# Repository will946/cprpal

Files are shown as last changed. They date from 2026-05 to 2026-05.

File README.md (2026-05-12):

# CPRPal — Real-Time CPR Feedback and Training Device

---

## Table of Contents

- [Project Overview](#project-overview)
- [Repository Structure](#repository-structure)
- [System Architecture](#system-architecture)
- [Hardware Components](#hardware-components)
- [Wiring and Pin Assignments](#wiring-and-pin-assignments)
- [PCB Design](#pcb-design)
- [Firmware](#firmware)
- [Operating Modes](#operating-modes)
- [User Operation](#user-operation)
- [Signal Processing](#signal-processing)
- [Power System](#power-system)
- [Cloud and Web Application](#cloud-and-web-application)
- [Setup and Installation](#setup-and-installation)
- [Library Dependencies](#library-dependencies)

---

## Project Overview

CPRPal is a portable, puck-shaped CPR coaching device designed to help untrained bystanders and CPR trainees perform chest compressions with correct force, rhythm, and body positioning during a cardiac emergency or training session.

Sudden cardiac arrest is responsible for approximately 93% of out-of-hospital cardiac arrest deaths. Survival probability drops roughly 10% per minute without CPR or AED intervention, yet only about 3% of the U.S. population is CPR certified annually. CPRPal addresses this gap by providing real-time, easy-to-interpret feedback that requires no prior training to use.

The device is placed between the rescuer's hands and the patient's sternum during chest compressions. It measures compression force directly using a load cell, tracks body posture using a 9-DOF IMU, monitors for heartbeat presence using a PPG optical sensor, and delivers feedback through a color-coded NeoPixel LED ring, a 2.8" TFT LCD display, and a 100 BPM audio metronome buzzer.

**Emergency Mode** operates fully standalone with no Wi-Fi required, providing immediate real-time feedback the moment the button is pressed.

**Training Mode** connects to Wi-Fi, runs a 2-minute guided session, and uploads averaged session metrics to an Azure-hosted cloud dashboard for review.

The final prototype measures 4.5" x 4.5" x 2.25" and runs for over 15 hours on four AA batteries at a normal operating draw of approximately 155 mA.

CPRPal Demo: https://drive.google.com/file/d/1d1auYhc-_jhG4WK9BlywpUfyi4_rIxLO/view?usp=sharing
(Note video isn't perfectly sync with operation)

| Rendering | Final Build |
|---|---|
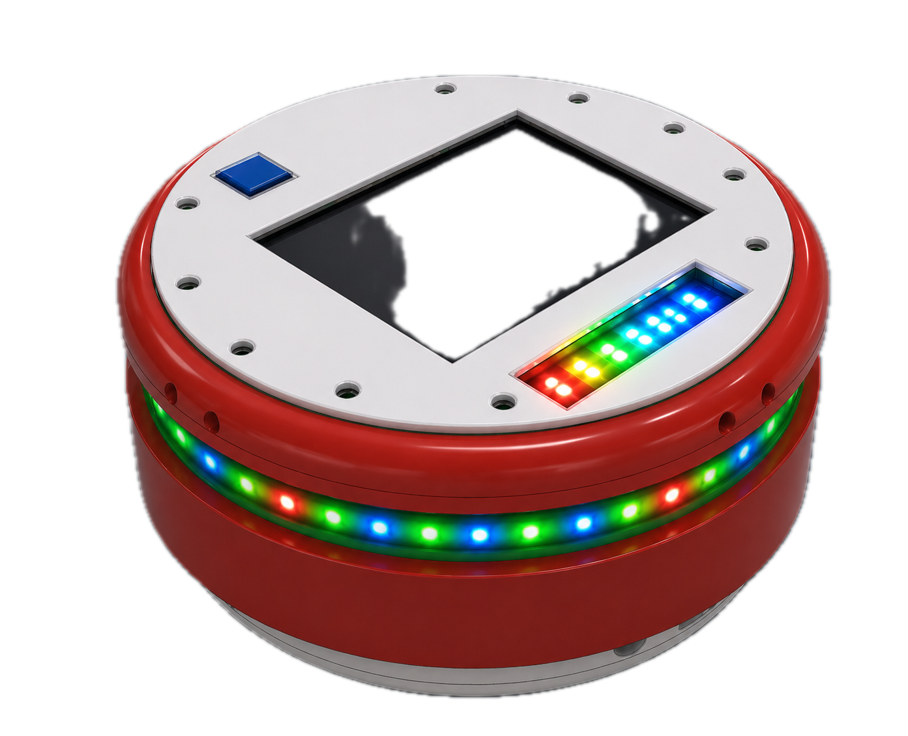
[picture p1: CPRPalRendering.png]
CPRPal Rendering
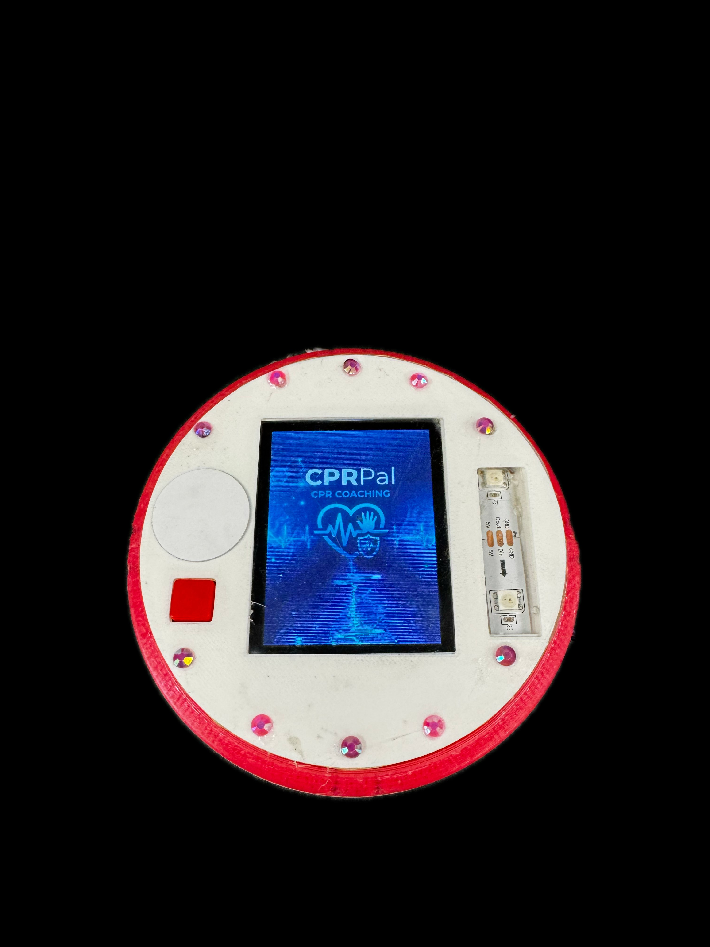
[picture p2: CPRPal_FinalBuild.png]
CPRPal Final Build
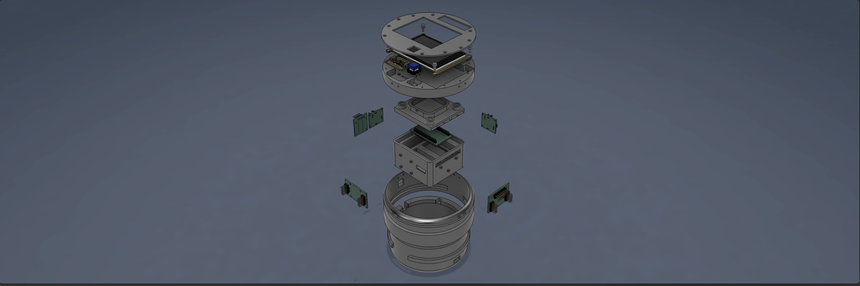
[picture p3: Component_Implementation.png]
Exploded View
|  |  | 

---

## Repository Structure

```
CPRPal/
├── 3DModel/
│   └── Mechanical enclosure and CAD files
│       - Top shell with lattice structure and LCD/button/LED cutouts
│       - Bottom shell with battery pocket, support beams, and hard stops
│       - Full assembly files for PLA 3D printing
│
├── ArduinoCode/
│   └── CPRPal.ino — Main ESP32 firmware (FreeRTOS-based)
│       - Sensor integration (HX711, BNO055, PPG)
│       - Real-time signal processing and CPM detection
│       - LED and display feedback systems
│       - Emergency and Training mode logic
│       - Power management and idle sleep
│       - HTTP cloud upload for training sessions
│
├── ArduinoWebsite/
│   └── Azure Static Web App source code
│       - Frontend dashboard (HTML/CSS/JS)
│       - Azure Function API endpoint
│       - Receives HTTP POST from ESP32
│       - Displays training session summary
│
├── PartsList/
│   └── Bill of Materials (BOM) and component references
│
└── PCBFiles/
    └── Full circuit schematics and PCB layout files
        - CPRPal_PCB_Sch — complete schematic
        - Panelized 6-board layout for JLCPCB fabrication
        - Custom PCB footprints and 3D component models
```

---

## System Architecture

CPRPal uses a dual-core FreeRTOS architecture on the Arduino Nano ESP32-S3.

### Core 0 — Sensor Acquisition and Processing

All time-critical sensor tasks run on Core 0 to prevent display rendering overhead from introducing jitter into sensor sampling.

| Task | Function | Sample Rate |
|---|---|---|
| `taskHX711` | Load cell reading, EMA filtering, CPM detection, idle detection | ~80 Hz |
| `taskIMU` | BNO055 orientation reading, tilt computation, posture status | ~40 Hz |
| `taskPPG` | PPG sampling, adaptive peak detection, BPM estimation | ~50 Hz |
| `taskBuzzer` | 100 BPM metronome via LEDC PWM, rhythm LED strip sync | 100 BPM |

### Core 1 — User Interface and Control

The Arduino `loop()` function runs on Core 1 and handles all output rendering:

- TFT display refresh at 10 Hz
- NeoPixel force bar graph refresh at 40 Hz
- Mode selection and session control logic
- Training session timer and metric accumulation
- Serial calibration commands

### Shared State and Synchronization

All shared sensor variables use the `g_` prefix, are declared `volatile`, and are protected by the FreeRTOS mutex `xDataMutex`. A second mutex `xWireMutex` serializes I2C bus access between `taskIMU` and any other bus user. This two-mutex architecture prevents data races while minimizing lock hold time.

---

## Hardware Components

| Component | Part | Purpose |
|---|---|---|
| Microcontroller | Arduino Nano ESP32-S3 | Main processing, Wi-Fi, dual-core FreeRTOS |
| Force Sensor | Half-bridge strain gauge load cell (120 lb) | Direct compression force measurement |
| Load Cell Amplifier | HX711 24-bit ADC | Amplifies and digitizes load cell signal at 80 SPS |
| IMU | Adafruit BNO055 9-DOF Fusion Breakout | Orientation, tilt detection, motion artifact rejection |
| Pulse Sensor | Pulse Sensor Amped (PPG) | Supplemental heartbeat detection |
| Display | Adafruit 2.8" ILI9341 TFT LCD | Real-time prompts and numeric status |
| LED Strips | Adafruit NeoPixel WS2812B (18 total) | Force bar (15 px) and rhythm metronome (3 px) |
| Buzzer | Piezo buzzer | 100 BPM audio metronome |
| Power Regulation | TPS63070 buck-boost converter x2 | Regulated 3.3V and 5V rails from 4xAA batteries |
| Reverse Protection | LM66200 ideal diode x2 | Prevents USB-to-battery reverse current |
| Storage | SanDisk 32GB microSD | Boot animation BMP frames |
| Battery | 4xAA alkaline | 10+ hours runtime at normal operating load |
| Enclosure | PLA 3D print | 4.7" x 4.7" x 2.4" puck housing |

---

## Wiring and Pin Assignments

### ESP32 GPIO Map

| Pin | Peripheral | Function |
|---|---|---|
| GPIO2 | HX711 CLK | Load cell clock |
| GPIO3 | HX711 DOUT | Load cell data |
| GPIO4 | SD Card CS | microSD chip select |
| GPIO6 (D6) | Start Button | Mode selection (active low, internal pull-up) |
| GPIO9 | ILI9341 DC | TFT data/command select |
| GPIO10 | ILI9341 CS | TFT chip select |
| GPIO19 | Buzzer | LEDC PWM channel 0, 2 kHz |
| GPIO21 | PPG LED indicator | Heartbeat flash LED |
| GPIO23 | PPG Sensor | Analog ADC input |
| GPIO2 (LED_PIN) | NeoPixel force bar | 15-pixel WS2812B data |
| GPIO4 (RHYTHM) | NeoPixel rhythm strip | 3-pixel WS2812B data |
| A4 (SDA) | BNO055 SDA | I2C data, 400 kHz |
| A5 (SCL) | BNO055 SCL | I2C clock, 400 kHz |

### I2C Bus

- BNO055 IMU address 0x28
- 10 kOhm pull-up resistors on SDA and SCL
- Bus speed 400 kHz (fast mode)
- External 32.768 kHz crystal for improved BNO055 sensor fusion accuracy

### SPI Bus

- ILI9341 TFT LCD: DC on GPIO9, CS on GPIO10
- microSD: CS on GPIO4
- Both share the hardware SPI bus

### Load Cell Wiring (Half-Bridge)

| Wire Color | HX711 Pin | Function |
|---|---|---|
| RED | E+ | Excitation positive |
| BLACK | E- | Excitation negative |
| WHITE | A- | Signal negative (differential) |
| GREEN | A+ | Signal positive (differential) |
| YELLOW | GND | Common ground reference |

Two 1 kOhm resistors on the HX711 board complete the Wheatstone bridge by providing the two fixed-impedance legs of the half-bridge configuration.

---

## PCB Design

CPRPal uses a custom panelized PCB fabricated by JLCPCB, separated into six press-fit sub-boards using mouse-bite breakaway tabs. Each sub-board can be removed and replaced independently without additional soldering.

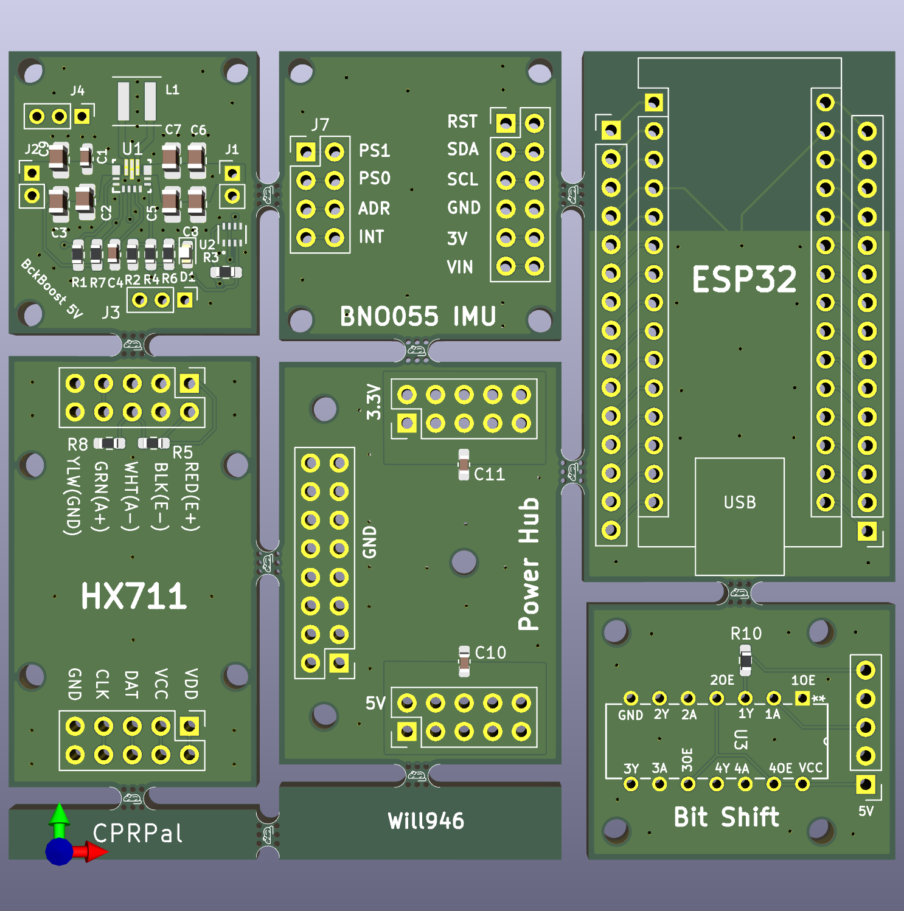
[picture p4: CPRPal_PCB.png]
PCB Panel Layout


### Sub-Board Summary

| Board | Key Components | Output |
|---|---|---|
| 3.3V BuckBoost | TPS63070, LM66200, 213k/365k feedback divider, decoupling caps, 1.5uH inductor | Regulated 3.3V rail |
| 5V BuckBoost | TPS63070, LM66200, alternate feedback divider, decoupling caps, 1.5uH inductor | Regulated 5V rail |
| Power Hub | Distribution headers, 10uF X5R decoupling caps x2 | Common power and ground plane |
| HX711 | HX711 IC, 1kOhm bridge resistors, DOUT/CLK headers | Load cell ADC interface |
| BNO055 IMU | BNO055 breakout, 10kOhm I2C pull-ups, 32.768kHz crystal | Euler angle outputs via I2C |
| ESP32 | Nano ESP32-S3 socket, USB passthrough | Main MCU |
| Bit Shift | Logic level shifter | 3.3V to 5V NeoPixel data translation |

### Component Footprints

#### 3.3V and 5V BuckBoost Boards
| Reference | Component | Footprint |
|---|---|---|
| U1 | TPS63070 — Buck-boost converter | SOT-23-8 |
| U2 | LM66200 — Ideal diode controller | SOT-23-6 |
| L1 | 1.5 µH inductor | Inductor_SMD 4x4mm |
| R1, R2 | Feedback divider resistors (213k / 365k for 3.3V; alternate values for 5V) | 0402 |
| R3 | Current sense resistor | 0402 |
| R4, R6, R7 | Bias/compensation resistors | 0402 |
| C1–C6 | Decoupling and compensation capacitors | 0402 |
| C7 | Output bulk capacitor | 0805 |
| D1 | Schottky diode | SOD-123 |
| J1, J2, J3, J4 | Power input/output headers | PinHeader 1x02 2.54mm |

#### Power Hub Board
| Reference | Component | Footprint |
|---|---|---|
| C10, C11 | 10 µF X5R decoupling capacitors | 0805 |
| J (3.3V) | 3.3V distribution header | PinHeader 2x05 2.54mm |
| J (5V) | 5V distribution header | PinHeader 2x05 2.54mm |
| J (GND) | Ground distribution header | PinHeader 1x08 2.54mm |

#### HX711 Board
| Reference | Component | Footprint |
|---|---|---|
| U1 | HX711 — 24-bit ADC | SOP-16 |
| R5, R8 | 1 kΩ Wheatstone bridge completion resistors | 0402 |
| J (VDD, VCC, DAT, CLK, GND) | MCU interface header | PinHeader 1x05 2.54mm |
| J (RED, BLK, WHT, GRN, YLW) | Load cell wire header | PinHeader 1x05 2.54mm |

#### BNO055 IMU Board
| Reference | Component | Footprint |
|---|---|---|
| U1 | BNO055 — 9-DOF IMU | LGA-28 (custom) |
| X1 | 32.768 kHz crystal | Crystal SMD 3.2x1.5mm |
| R1, R2 | 10 kΩ I2C pull-up resistors | 0402 |
| J7 | Configuration header (PS0, PS1, ADR, INT) | PinHeader 1x04 2.54mm |
| J (RST, SDA, SCL, GND, 3V, VIN) | MCU interface header | PinHeader 1x06 2.54mm |

#### ESP32 Board
| Reference | Component | Footprint |
|---|---|---|
| U1 | Arduino Nano ESP32-S3 | Custom dual-row female socket, 2x15 2.54mm |
| J (USB) | USB-C passthrough cutout | USB-C receptacle footprint |
| J (left, right) | GPIO breakout headers | PinHeader 1x15 2.54mm x2 |

#### Bit Shift Board
| Reference | Component | Footprint |
|---|---|---|
| U3 | 74AHCT125 — Quad level shifter | SOIC-14 |
| R10 | Pull-down resistor | 0402 |
| J (input) | 3.3V NeoPixel data input header | PinHeader 1x02 2.54mm |
| J (output) | 5V NeoPixel data output header | PinHeader 1x02 2.54mm |
| J (VCC, GND) | Power headers | PinHeader 1x02 2.54mm |

### Power Architecture

Two independent TPS63070 buck-boost converters are used instead of a single converter with an LDO post-regulator. This improves efficiency across the full 4xAA discharge range (approximately 6V fully charged to 4.8V near end of life), since the buck-boost topology maintains tight output regulation without the linear losses an LDO would introduce at shrinking headroom.

- 3.3V rail powers: ESP32-S3, BNO055 IMU, PPG sensor, piezo buzzer
- 5V rail powers: ILI9341 LCD, NeoPixel strips (18 px total), HX711 amplifier

---

## Firmware

The firmware is a single Arduino sketch located in `ArduinoCode/CPRPal.ino`. It is written in C++ using the Arduino framework for ESP32 and relies on FreeRTOS task management, mutex-protected shared state, and the ESP32's LEDC hardware PWM peripheral for the buzzer metronome.

### Key Constants

```cpp
// Force feedback thresholds (lbs)
const float FORCE_THRESHOLD_LB      = 30.0f;   // Rising edge detection
const float FORCE_LOW_OK            = 75.0f;   // Below = TOO LIGHT (yellow)
const float FORCE_HIGH_OK           = 110.0f;  // Above = TOO STRONG (red)

// CPM thresholds
const float CPM_LOW_OK              = 100.0f;  // Below = TOO SLOW
const float CPM_HIGH_OK             = 120.0f;  // Above = TOO FAST
const unsigned long CPM_DEBOUNCE_MS = 180UL;   // Anti-bounce window
const int CPM_INTERVAL_COUNT        = 6;       // Rolling average window size

// Tilt feedback
const float TILT_WARN_DEG           = 8.0f;    // Above = ADJUST

// Timing
const unsigned long IDLE_TIMEOUT_MS     = 20000UL;  // 20s inactivity -> idle
const unsigned long TRAINING_SESSION_MS = 120000UL; // 2-minute session
const unsigned long TRAINING_SAMPLE_MS  = 3000UL;   // Sample every 3s
const unsigned long TRAINING_HOLD_MS    = 3000UL;   // Button hold -> Training

// Buzzer metronome
#define BUZZER_FREQ_HZ    2000  // 2 kHz tone
#define BUZZER_BEEP_MS    30    // On-time per beat in ms
#define BUZZER_PERIOD_MS  600   // Full period = 100 BPM

// Load cell
float calibration_factor = 6500; // Raw counts per pound-force (empirical)
```

### Live Serial Calibration Commands

The calibration factor can be adjusted without reflashing firmware using the Serial Monitor at 115200 baud:

| Key | Action |
|---|---|
| `+` or `a` | Increase calibration factor by 10 |
| `-` or `z` | Decrease calibration factor by 10 |
| `t` or `T` | Tare the scale (zero current load) |
| `r` or `R` | Reset session peak weight |

### EMA Filter

Raw load cell readings are smoothed before any threshold detection:

```
w_filtered[n] = 0.75 * w_filtered[n-1] + 0.25 * w_raw[n]
```

Smoothing factor alpha = 0.25 was chosen empirically to balance noise rejection against compression onset detection latency.

### CPM Detection Algorithm

1. EMA-filtered force crosses above FORCE_THRESHOLD_LB (30 lb) — rising edge detected
2. 180ms debounce window prevents double-counting from signal ringing near threshold
3. Inter-edge interval converted to instantaneous CPM: `CPM = 60000 / delta_t_ms`
4. Stored in 6-entry circular buffer; rolling CPM = arithmetic mean of buffer entries
5. If no compression detected for 2000ms, CPM resets to zero and buffer clears

### IMU Baseline Calibration

On startup, 100 BNO055 orientation samples are captured (after 50 warm-up discards) and averaged as the resting baseline. All subsequent readings are deltas from this baseline so tilt feedback is relative to device placement on the patient, not absolute gravity direction.

- Tilt magnitude = sqrt(delta_roll² + delta_pitch²)
- Above 5 degrees triggers ADJUST on LCD
- Above 10 degrees triggers LEAN on LCD

### PPG Detection Algorithm

1. ADC sampled at ~50 Hz, 12-bit resolution, 3.6V full-scale attenuation
2. 10-sample moving average applied for noise reduction
3. Adaptive baseline tracks slow DC component of signal
4. Adaptive peak envelope tracks signal upper bound
5. Beat detected on rising edge exceeding 55% of amplitude above baseline
6. Flag resets when signal falls below 35% of amplitude (hysteresis)
7. BPM = average of 4 most recent valid inter-beat intervals
8. BPM zeroed after 3.5s without a detected beat
9. Finger contact confirmed when ADC reading exceeds FINGER_ON threshold (1700)

---

## Operating Modes

### Boot Sequence

On power-on the device performs the following sequence automatically:

1. Serial initialization and reset reason diagnostic printout to serial monitor
2. I2C bus initialization at 400 kHz on pins A4 and A5
3. BNO055 initialization and external crystal enable
4. SPI bus and TFT display initialization
5. Boot animation — 8 BMP frames loaded sequentially from microSD, 1.25s per frame
6. NeoPixel strip initialization at 40/255 brightness
7. HX711 initialization, power-up, and tare to zero
8. FreeRTOS sensor tasks spawned on Core 0
9. Mode selection screen displayed
10. User selects mode via button
11. IMU orientation baseline captured in current resting position

### Emergency Mode

Activated by a short press of the start button.

- Wi-Fi fully disabled — no radio activity during emergency
- 100 BPM metronome starts immediately
- Live CPM, force, tilt, and PPG status shown on TFT display
- NeoPixel force bar updates at 40 Hz
- After 20s of inactivity (no load cell change exceeding 10 lb), all sensor tasks are suspended in RAM and device enters software idle mode at approximately 95 mA
- To wake: hold button for 2 seconds; all peripherals reinitialize and device returns to mode selection

### Training Mode

Activated by holding the button for 3 seconds.

- Wi-Fi connection attempted with 10s timeout
- If no network found: graceful offline fallback, session runs locally, no upload at end
- 2-minute timed session with countdown timer displayed on LCD bottom-right
- Sensor metrics sampled every 3s into running sum accumulators
- At session end: averages computed, JSON serialized manually, HTTP POST sent to Azure endpoint
- Session summary displayed on LCD regardless of upload success
- Wi-Fi fully shut down after upload; device returns to mode selection

---

## User Operation

### Emergency Mode Step-by-Step

1. Remove CPRPal from first aid kit and slide power switch on. Keep device still on a flat surface during the ~5 second boot and IMU calibration sequence.
2. Call 911 immediately or direct a bystander to call. Do not delay emergency services.
3. Place CPRPal face-up on the center of the patient's chest, between the nipple line, with the LCD visible to you.
4. Short-press the start button once. Emergency Mode begins and the metronome starts at 100 BPM.
5. Place both hands on top of the device and compress in time with the beep and amber LED ring.
6. Watch the side LED bar: yellow = push harder, green = good depth, red = ease up.
7. Watch LCD TILT row: ADJUST or LEAN means recheck your body position and ensure force is going straight down.
8. Watch LCD PPG row: Heartbeat detect means consider pausing to reassess for pulse.
9. Continue compressions until EMS arrives or AED is ready.

### Training Mode Step-by-Step

1. Power on and hold button for 3 seconds until "Training selected" appears on LCD.
2. Device connects to Wi-Fi and displays IP address on successful connection.
3. Scan QR code on device or navigate to the dashboard URL on a phone or computer.
4. Begin compressions following the same LED and LCD feedback as Emergency Mode.
5. 2-minute countdown timer shown at bottom right of LCD throughout session.
6. At session end, summary shown on LCD and data uploaded to dashboard if Wi-Fi available.

### Feedback Reference

| Channel | States | Meaning |
|---|---|---|
| LCD — CPM | WAITING / TOO SLOW / GOOD / TOO FAST | Compression rate guidance toward 100-120 CPM |
| LCD — Force | TOO LIGHT / GOOD / TOO STRONG | Compression depth guidance toward AHA target |
| LCD — Tilt | GOOD / ADJUST / LEAN | Posture and off-axis warning |
| LCD — PPG | BPM value / Heartbeat detect / Missing heartbeat | Supplemental pulse status |
| NeoPixel bar | Yellow / Green / Red | Visual force classification |
| Buzzer + rhythm LEDs | 100 BPM beep + amber flash | Compression pacing metronome |

---

## Signal Processing

### Force Classification

| Force Range | LED Color | LCD Status | Meaning |
|---|---|---|---|
| < 5 lb | Off | — | No significant contact |
| 5–75 lb | Yellow | TOO LIGHT | Insufficient compression force |
| 75–110 lb | Green | GOOD | Target depth range |
| > 110 lb | Red | TOO STRONG | Excessive force |

### CPM Classification

| CPM Range | LCD Status |
|---|---|
| < 1 | WAITING |
| 1–99 | TOO SLOW |
| 100–120 | GOOD |
| > 120 | TOO FAST |

### Tilt Classification

| Tilt Magnitude | LCD Status |
|---|---|
| < 5 degrees | GOOD |
| 5–10 degrees | ADJUST |
| > 10 degrees | LEAN |

---

## Power System

### Rail Assignments

| Rail | Powered Components |
|---|---|
| 3.3V | ESP32-S3, BNO055 IMU, PPG sensor, piezo buzzer |
| 5V | ILI9341 LCD, NeoPixel strips (18 px total), HX711 amplifier |

### Power Budget

| Operating Mode | Current Draw | Notes |
|---|---|---|
| Peak startup | ~235 mA | Boot animation with full brightness LEDs and LCD |
| Normal (Emergency Mode) | ~155 mA | Colored LEDs at 40/255, dim LCD, all sensors active |
| Idle (tasks suspended) | ~95 mA | LCD dim showing idle screen, ESP32 running, all else off |
| Training Mode | ~195 mA | Normal + 40 mA Wi-Fi radio, no idle mode |

At 155 mA normal draw with a 2700 mAh 4xAA pack, theoretical runtime is approximately 17 hours. Measured battery life exceeded 10 hours under mixed-use testing.

---

## Cloud and Web Application

### Dashboard URL

```
https://gentle-stone-0c20e761e.6.azurestaticapps.net/
```

The dashboard is a static web application hosted on Microsoft Azure Static Web Apps using the free tier only. No charges are incurred.

### Data Flow

```
ESP32 collects sensor data every 3s during Training Mode session
  -> Averages computed at 2-minute session end
  -> JSON payload manually serialized (no external library)
  -> HTTP POST to Azure Function API endpoint
  -> Azure processes and stores payload
  -> Dashboard displays session summary
```

### JSON Payload Format

```json
{
  "deviceId": "nano-esp32-test",
  "timestamp": "123456789",
  "mode": "TRAINING",
  "sessionType": "summary",
  "ppg": 1800,
  "imuY": 2.5,
  "imuZ": -1.2,
  "compressionRate": 110,
  "compressionDepth": 85.3,
  "recoil": 1,
  "status": "Good compressions",
  "sampleCount": 40,
  "sessionDurationMs": 120000
}
```

### Status String Logic

| Condition | Status Field Value |
|---|---|
| Rate > 125 CPM or depth > 6.2 lb | `"Bad: too fast/deep"` |
| Rate < 100 CPM or depth < 5.0 lb or recoil == 0 | `"Warn: shallow/recoil"` |
| All within range | `"Good compressions"` |

### Offline Fallback

If Wi-Fi is unavailable when Training Mode is entered:

1. Device displays offline warning on LCD
2. Full 2-minute session runs locally with all normal feedback active
3. Session summary displayed on LCD at session end
4. HTTP POST upload skipped

---

## Setup and Installation

### Requirements

- Arduino IDE 2.x
- Arduino ESP32 board package installed via Boards Manager
  - Search for `esp32` by Espressif Systems
  - Select board: **Arduino Nano ESP32**

### Step 1 — Install Required Libraries

Open Arduino IDE and go to Sketch -> Include Library -> Manage Libraries. Search for and install each of the following:

| Library | Author |
|---|---|
| Adafruit BNO055 | Adafruit |
| Adafruit BusIO | Adafruit |
| Adafruit EPD | Adafruit |
| Adafruit FT6206 Library | Adafruit |
| Adafruit GFX Library | Adafruit |
| Adafruit HX8357 Library | Adafruit |
| Adafruit ILI9341 | Adafruit |
| Adafruit ImageReader Library | Adafruit |
| Adafruit NeoMatrix | Adafruit |
| Adafruit NeoPixel | Adafruit |
| Adafruit seesaw Library | Adafruit |
| Adafruit SH110X | Adafruit |
| Adafruit SPIFlash | Adafruit |
| Adafruit SSD1331 OLED Driver Library for Arduino | Adafruit |
| Adafruit SSD1351 library | Adafruit |
| Adafruit ST7735 and ST7789 Library | Adafruit |
| Adafruit STMPE610 | Adafruit |
| Adafruit TouchScreen | Adafruit |
| Adafruit TSC2007 | Adafruit |
| Adafruit Unified Sensor | Adafruit |
| HX711 | bogde |
| PulseSensor Playground | World Famous Electronics |
| SdFat - Adafruit Fork | Adafruit |

> WiFi and HTTPClient are included with the ESP32 Arduino core and do not require separate installation.

### Step 2 — Prepare the microSD Card

The boot animation requires 8 BMP image files placed in the root of a FAT32-formatted microSD card. Name the files exactly as follows:

```
/Step0.bmp
/Step1.bmp
/Step2.bmp
/Step3.bmp
/Step4.bmp
/Step5.bmp
/Step6.bmp
/Step7.bmp
```

Each image should be a 24-bit BMP at 240x320 pixels to match the ILI9341 display resolution. If the SD card fails to mount, the firmware will halt and display an error on the TFT screen.

### Step 3 — Configure Wi-Fi Credentials

Open `ArduinoCode/CPRPal.ino` and locate the following lines near the top of the file:

```cpp
const char* WIFI_SSID     = "YOUR_SSID_HERE";
const char* WIFI_PASSWORD = "YOUR_PASSWORD_HERE";
```

Replace with your Wi-Fi network credentials. Wi-Fi is only used during Training Mode. Emergency Mode runs fully offline regardless of these settings.

> Note: The ESP32 posts directly to the Azure cloud endpoint over any internet-connected Wi-Fi network. The viewing device does not need to be on the same network as the ESP32.

### Step 4 — Select Board and Port

In Arduino IDE:

1. Go to Tools -> Board -> esp32 -> Arduino Nano ESP32
2. Go to Tools -> Port -> select the correct COM port for your device
3. If the board is not recognized, hold the BOOT button on the ESP32 while connecting USB

### Step 5 — Flash Firmware

Click Upload in Arduino IDE. Open the Serial Monitor at 115200 baud to view boot diagnostics, reset reason history, sensor readings, and calibration output.

### Step 6 — Calibrate the Load Cell

1. Power on the device and let it boot fully
2. Open Serial Monitor at 115200 baud
3. Place a known weight on the device
4. Use `+` and `-` keys in Serial Monitor to adjust calibration factor until the displayed value matches the known weight
5. Note the final calibration factor and update `calibration_factor` in the sketch to save it permanently

---

## Library Dependencies

| Library | Purpose in CPRPal |
|---|---|
| Adafruit BNO055 | BNO055 IMU driver and Euler angle output |
| Adafruit BusIO | I2C/SPI abstraction layer required by Adafruit sensor libraries |
| Adafruit GFX Library | Core graphics primitives for TFT display rendering |
| Adafruit ILI9341 | ILI9341 TFT display driver |
| Adafruit ImageReader Library | BMP image loading from SD card for boot animation |
| Adafruit NeoPixel | WS2812B addressable LED control for force bar and rhythm strip |
| Adafruit NeoMatrix | NeoPixel matrix support (dependency) |
| Adafruit Unified Sensor | Unified sensor abstraction required by BNO055 driver |
| Adafruit SPIFlash | SPI flash support (alternative storage backend) |
| SdFat - Adafruit Fork | SD card FAT filesystem for microSD BMP loading |
| Adafruit EPD | E-paper display support (dependency) |
| Adafruit FT6206 Library | Capacitive touchscreen support (dependency) |
| Adafruit HX8357 Library | HX8357 display driver (dependency) |
| Adafruit seesaw Library | Adafruit seesaw breakout support (dependency) |
| Adafruit SH110X | OLED display driver (dependency) |
| Adafruit SSD1331 OLED Driver | SSD1331 OLED support (dependency) |
| Adafruit SSD1351 library | SSD1351 OLED support (dependency) |
| Adafruit ST7735 and ST7789 Library | ST77xx display drivers (dependency) |
| Adafruit STMPE610 | Touch controller support (dependency) |
| Adafruit TouchScreen | Resistive touchscreen support (dependency) |
| Adafruit TSC2007 | Touch controller support (dependency) |
| HX711 by bogde | HX711 load cell amplifier driver |
| PulseSensor Playground | PPG pulse sensor signal processing |

*CPRPal is a prototype device developed for educational purposes. It is not a certified medical device. Always call emergency services first in a cardiac emergency.*

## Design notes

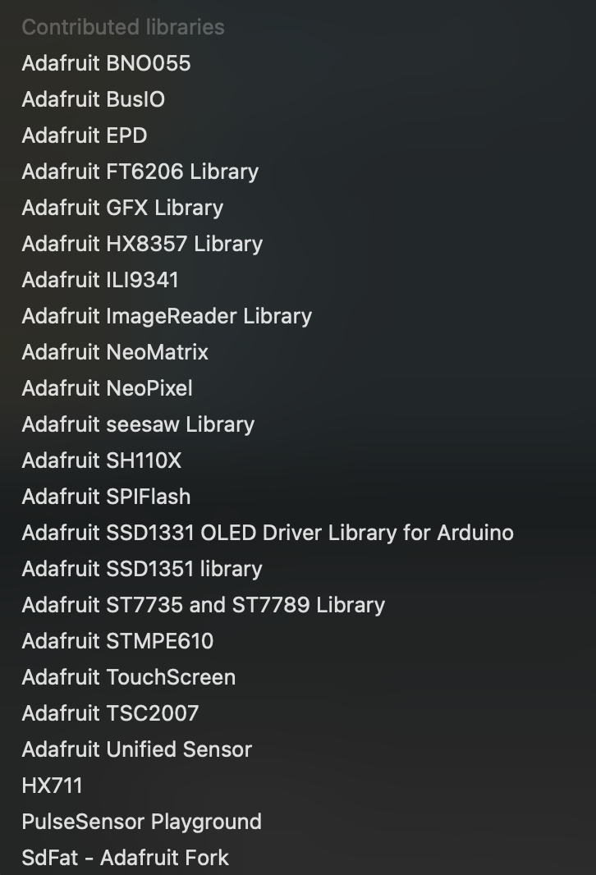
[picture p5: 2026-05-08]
Arduino_Code/Libraries.png

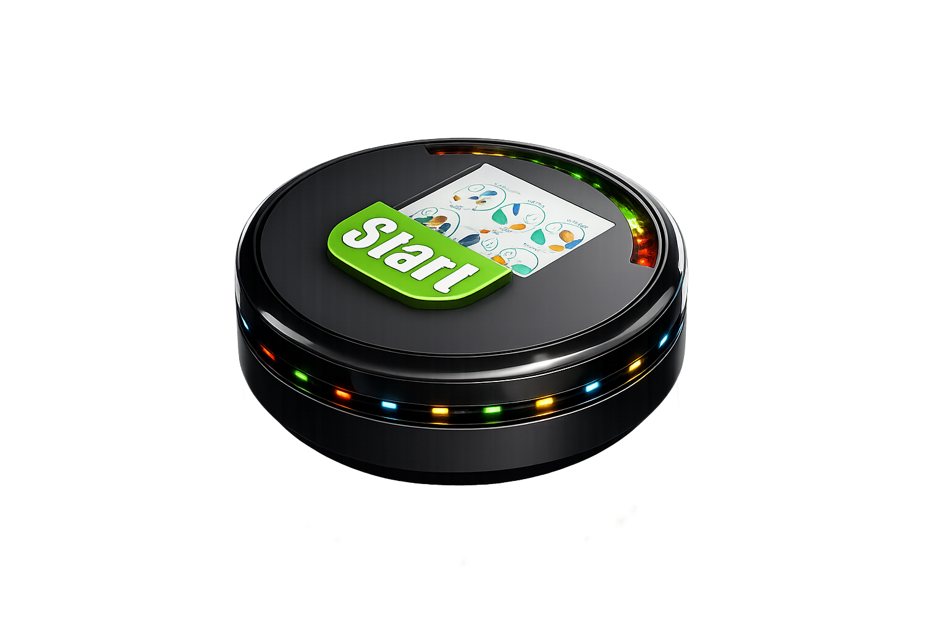
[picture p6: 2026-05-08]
CPRPal_Website_API/src/cpr-device-img.png

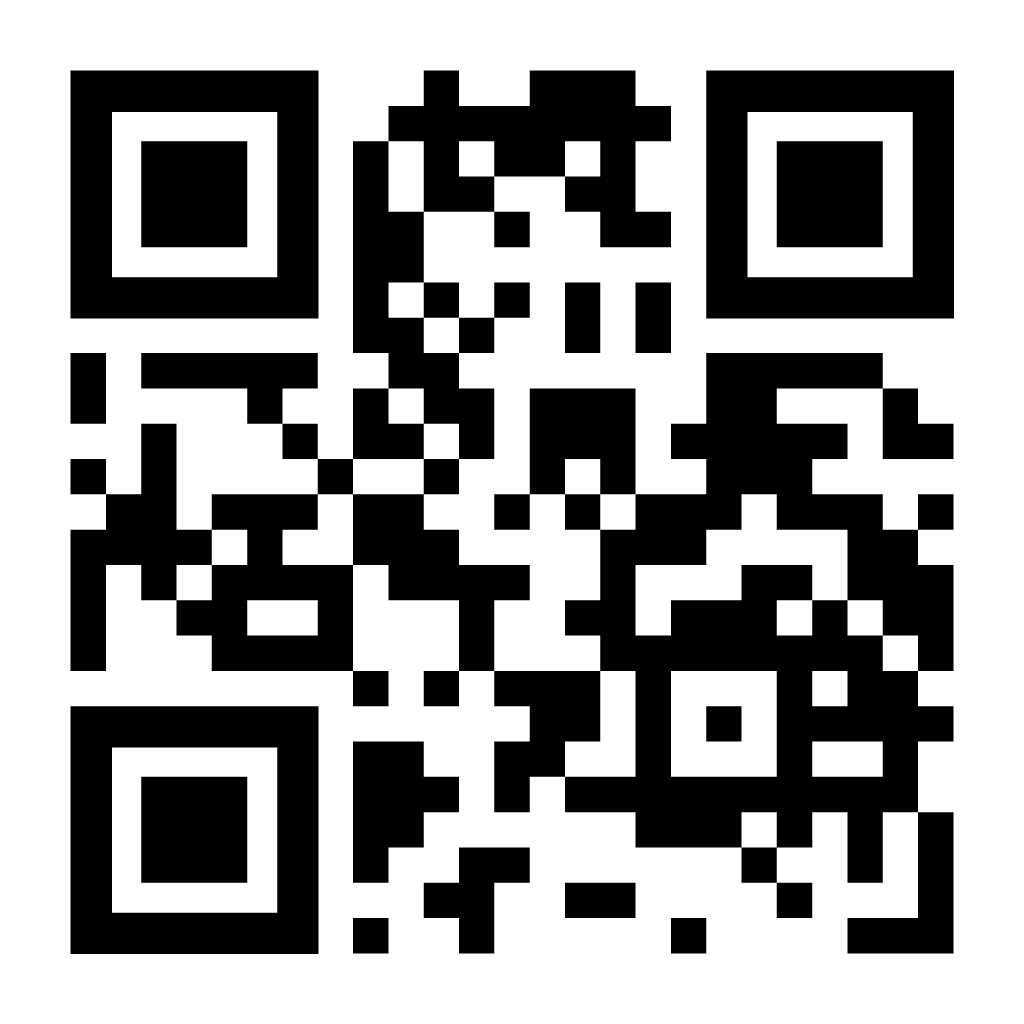
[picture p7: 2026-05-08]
CPRPal_Website_API/src/website-qr.png

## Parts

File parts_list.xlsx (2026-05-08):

Part Name | Manufacturer | SKU / Part Number | Supplier | Source URL
Arduino Nano ESP32 with Headers | Arduino | ABX00083 | Arduino Store | https://store-usa.arduino.cc/products/nano-esp32-with-headers
Load Sensor - 50kg (Generic) | Generic | SEN-10245 | SparkFun | https://www.sparkfun.com/load-sensor-50kg-generic.html
SparkFun Load Cell Amplifier - HX711 | SparkFun | SEN-13879 | SparkFun | https://www.sparkfun.com/sparkfun-load-cell-amplifier-hx711.html
Pulse Sensor Amped | Adafruit | 1093 | Adafruit | https://www.adafruit.com/product/1093
Adafruit 9-DOF Absolute Orientation IMU Fusion Breakout - BNO055 (STEMMA QT / Qwiic) | Adafruit | 4646 | Adafruit | https://www.adafruit.com/product/4646
Keystone Electronics Battery Holder (M65 Series) | Keystone Electronics | See M65 catalog p.28 | Keystone Electronics | https://www.keyelco.com/userAssets/file/M65p28.pdf
TI TPS63070 Buck-Boost Converter | Texas Instruments | TPS63070 | Texas Instruments | https://www.ti.com/product/TPS63070
Adafruit NeoPixel Digital RGB LED Strip - White 30 LED 1m | Adafruit | 2538 | Adafruit | https://www.adafruit.com/product/2538
Adafruit LM66200 Ideal Dual Diodes Breakout | Adafruit | 5830 | Adafruit | https://www.adafruit.com/product/5830
Colorful 12mm Square Tactile Button Switch Assortment - 15 pack | Adafruit | 1010 | Adafruit | https://www.adafruit.com/product/1010
2.8in TFT LCD with Touchscreen Breakout - ILI9341 | Adafruit | 1770 | Adafruit | https://www.adafruit.com/product/1770
Buzzer 5V - Breadboard Friendly | Adafruit | 1536 | Adafruit | https://www.adafruit.com/product/1536

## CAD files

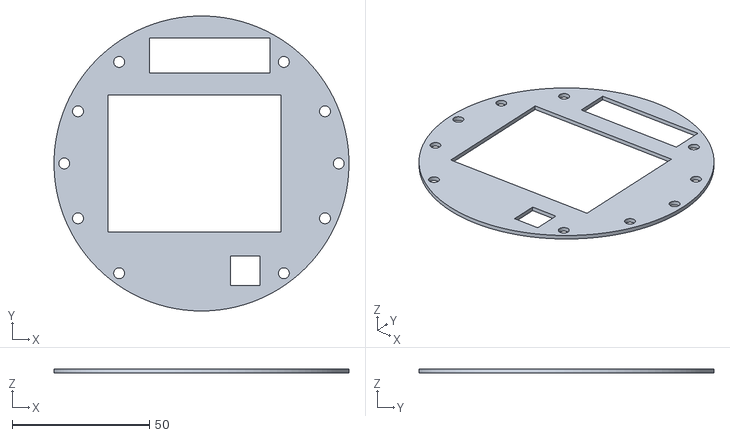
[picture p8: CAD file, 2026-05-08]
3D_Files/CoverPlate_V1.stl
107.5 x 107.5 x 1.50

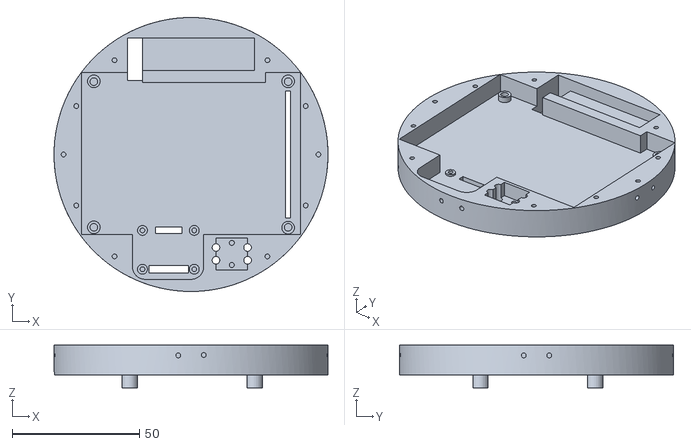
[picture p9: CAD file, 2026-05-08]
3D_Files/TopMount_V1.stl
107.5 x 107.5 x 16.8

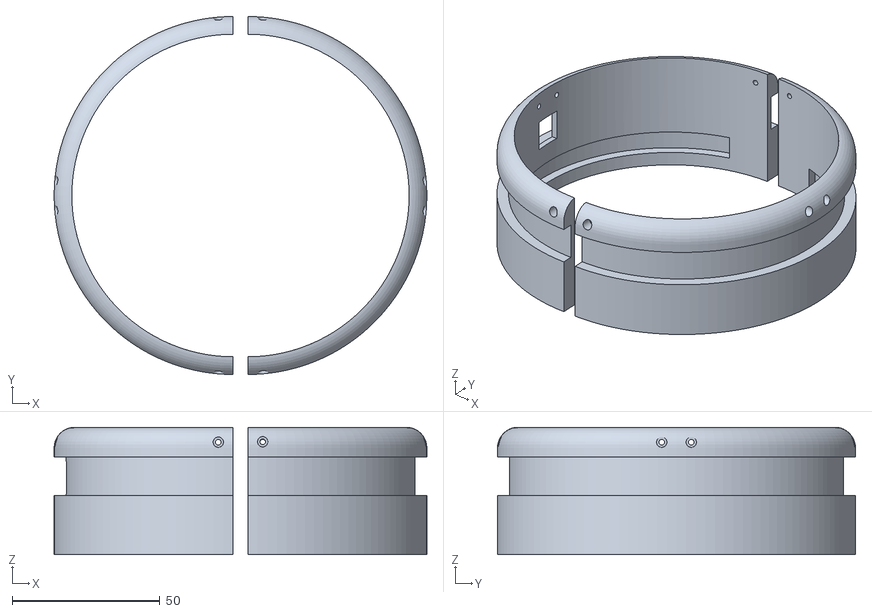
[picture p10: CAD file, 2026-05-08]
3D_Files/TopCover_V2.stl
126.0 x 121.0 x 43.0

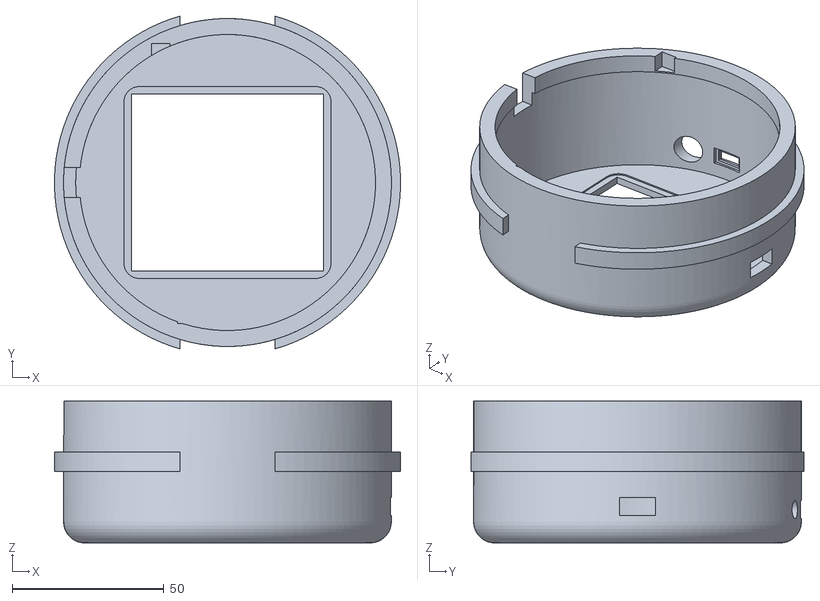
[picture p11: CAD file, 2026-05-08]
3D_Files/Body_V4.stl
113.9 x 109.6 x 46.8

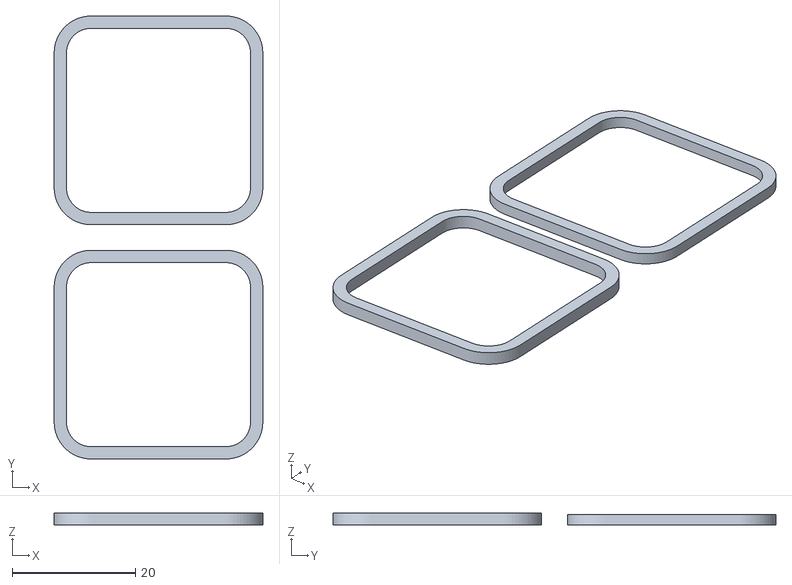
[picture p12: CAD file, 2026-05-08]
3D_Files/CellSpacer_V2.stl
33.8 x 71.8 x 2.00

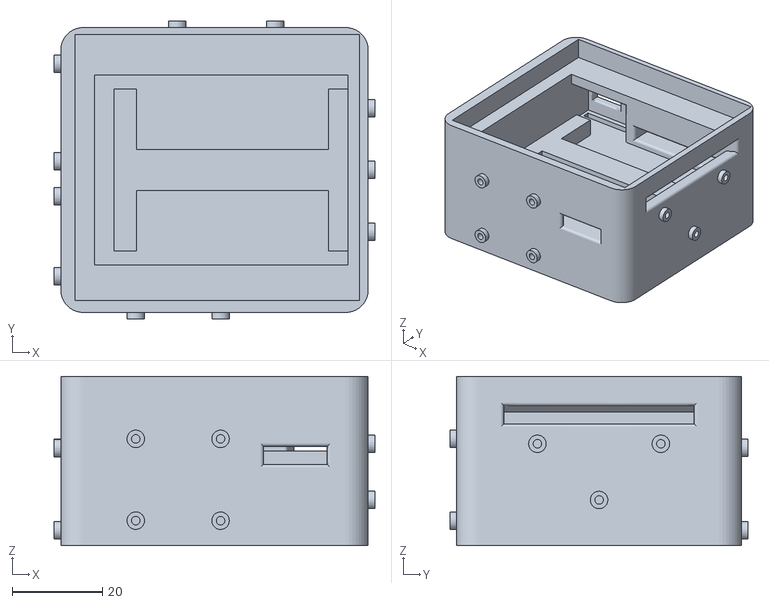
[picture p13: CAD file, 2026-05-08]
3D_Files/PCBMount_V1.stl
71.2 x 66.2 x 37.5

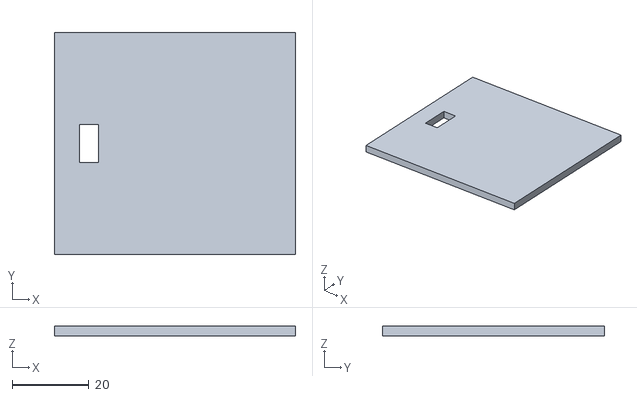
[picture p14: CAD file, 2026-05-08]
3D_Files/BatteryPlate_V1.stl
63.0 x 58.0 x 2.50

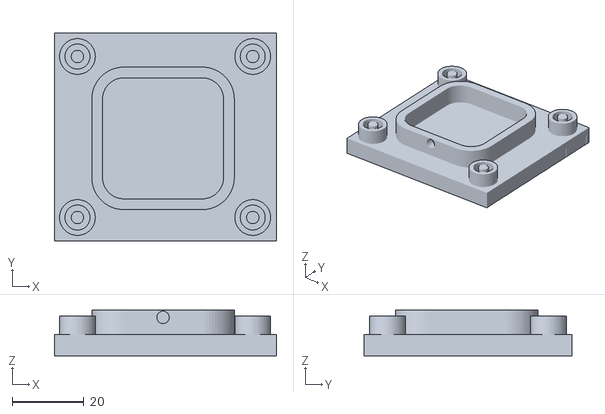
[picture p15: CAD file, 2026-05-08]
3D_Files/LoadcellMount_V2.stl
62.1 x 58.0 x 12.8

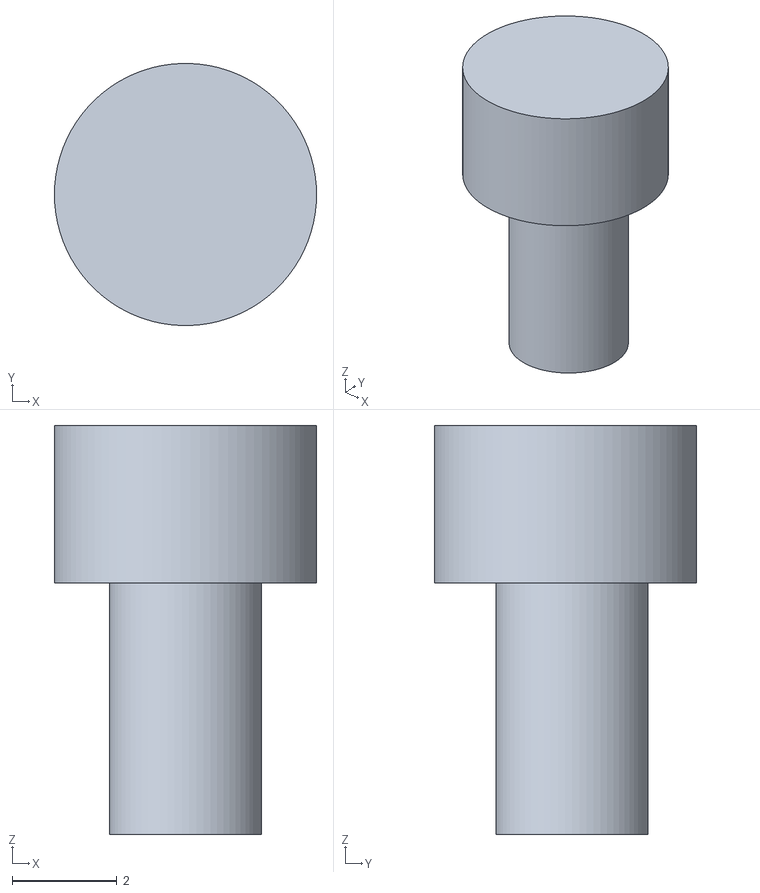
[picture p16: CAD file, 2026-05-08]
3D_Files/Screw_V1.stl
5.00 x 5.00 x 7.80

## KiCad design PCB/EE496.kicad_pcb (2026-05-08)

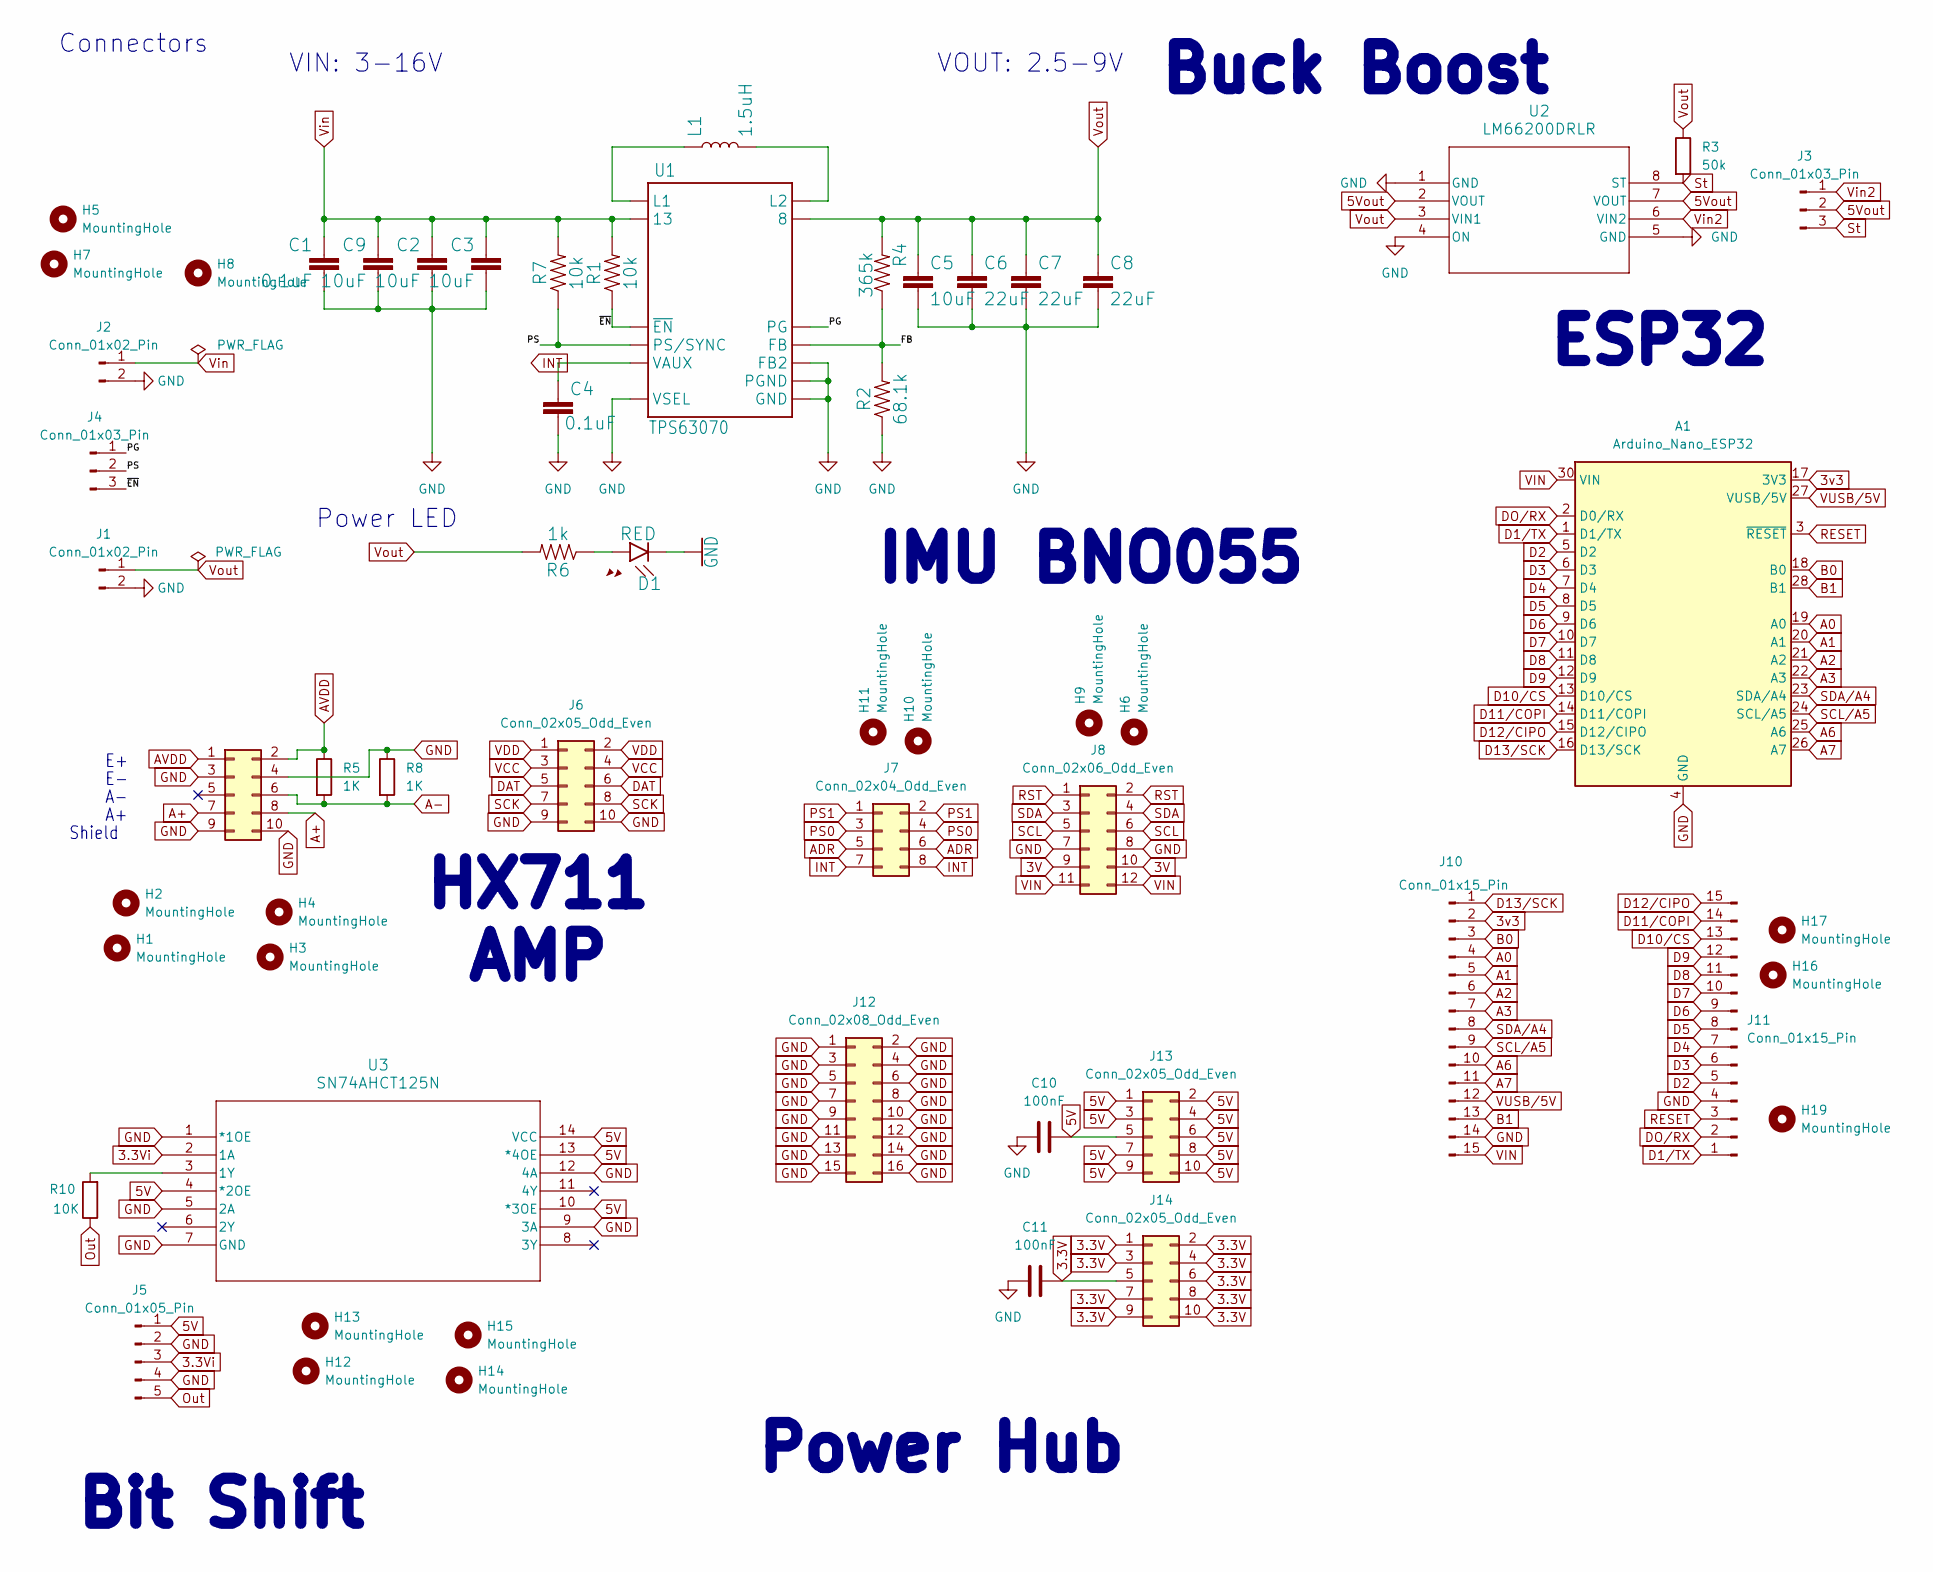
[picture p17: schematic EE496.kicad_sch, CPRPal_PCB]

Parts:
A1: Arduino_Nano_ESP32; Arduino_Nano
C1, C4: 0.1uF; C_0603_1608Metric_Pad1.08x0.95mm_HandSolder
C2, C3, C5, C9: 10uF; C_0805_2012Metric_Pad1.18x1.45mm_HandSolder
C6, C7, C8: 22uF; C_0805_2012Metric_Pad1.18x1.45mm_HandSolder
C10, C11: 100nF; C_0603_1608Metric_Pad1.08x0.95mm_HandSolder
D1: RED; LED_0603_1608Metric
H1, H2, H3, H4, H5, H6, H7, H8, H9, H10, H11, H12, H13, H14, H15, H16, H17, H19: MountingHole; MountingHole_2.2mm_M2
J1, J2: Conn_01x02_Pin; PinHeader_1x02_P2.00mm_Vertical
J3, J4: Conn_01x03_Pin; PinHeader_1x03_P2.00mm_Vertical
J5: Conn_01x05_Pin; PinHeader_1x05_P2.54mm_Vertical
J6, J9, J13, J14: Conn_02x05_Odd_Even; PinHeader_2x05_P2.54mm_Vertical
J7: Conn_02x04_Odd_Even; PinHeader_2x04_P2.54mm_Vertical
J8: Conn_02x06_Odd_Even; PinHeader_2x06_P2.54mm_Vertical
J10, J11: Conn_01x15_Pin; PinHeader_1x15_P2.54mm_Vertical
J12: Conn_02x08_Odd_Even; PinHeader_2x08_P2.54mm_Vertical
L1: 1.5uH; L_Coilcraft_XxL4020
R1, R7: 10k; R_0603_1608Metric_Pad0.98x0.95mm_HandSolder
R2: 68.1k; R_0603_1608Metric_Pad0.98x0.95mm_HandSolder
R3: 50k; R_0603_1608Metric_Pad0.98x0.95mm_HandSolder
R4: 365k; R_0603_1608Metric_Pad0.98x0.95mm_HandSolder
R5, R8: 1K; R_0603_1608Metric_Pad0.98x0.95mm_HandSolder
R6: 1k; R_0603_1608Metric_Pad0.98x0.95mm_HandSolder
R10: 10K; R_0603_1608Metric_Pad0.98x0.95mm_HandSolder
U1: TPS63070; RNM0015A
U2: LM66200DRLR; SOT-5X3_DRL_TEX-L
U3: SN74AHCT125N; N14

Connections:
3.3V: C11.2, J14.1, J14.2, J14.3, J14.4, J14.5, J14.6, J14.7, J14.8, J14.9, J14.10
3.3Vi: J5.3, U3.2 (1A)
3V: J8.9, J8.10
3v3: A1.17 (3V3), J10.2
5V: C10.2, J5.1, J13.1, J13.2, J13.3, J13.4, J13.5, J13.6, J13.7, J13.8, J13.9, J13.10, U3.4 (*2OE), U3.10 (*3OE), U3.13 (*4OE), U3.14 (VCC)
5Vout: J3.2, U2.2 (VOUT), U2.7 (VOUT)
/FB: R2.2, R4.1, U1.5 (FB)
/PG: J4.1, U1.2 (PG)
/PS: J4.2, R7.1, U1.1 (PS/SYNC)
/~EN: J4.3, R1.1, U1.14 (~EN)
A0: A1.19 (A0), J10.4
A1: A1.20 (A1), J10.5
A2: A1.21 (A2), J10.6
A3: A1.22 (A3), J10.7
A6: A1.25 (A6), J10.10
A7: A1.26 (A7), J10.11
A+: J9.7, J9.8
A-: J9.6, R5.2, R8.2
ADR: J7.5, J7.6
AVDD: J9.1, J9.2, R5.1
B0: A1.18 (B0), J10.3
B1: A1.28 (B1), J10.13
D1/TX: A1.1 (D1/TX), J11.1
D2: A1.5 (D2), J11.5
D3: A1.6 (D3), J11.6
D4: A1.7 (D4), J11.7
D5: A1.8 (D5), J11.8
D6: A1.9 (D6), J11.9
D7: A1.10 (D7), J11.10
D8: A1.11 (D8), J11.11
D9: A1.12 (D9), J11.12
D10/CS: A1.13 (D10/CS), J11.13
D11/COPI: A1.14 (D11/COPI), J11.14
D12/CIPO: A1.15 (D12/CIPO), J11.15
D13/SCK: A1.16 (D13/SCK), J10.1
DAT: J6.5, J6.6
DO/RX: A1.2 (D0/RX), J11.2
GND: A1.4 (GND), A1.29 (GND), C1.2, C2.2, C3.2, C4.2, C5.2, C6.2, C7.2, C8.2, C9.2, C10.1, C11.1, D1.2 (C), J1.2, J2.2, J5.2, J5.4, J6.9, J6.10, J8.7, J8.8, J9.3, J9.4, J9.9, J9.10, J10.14, J11.4, J12.1, J12.2, J12.3, J12.4, J12.5, J12.6, J12.7, J12.8, J12.9, J12.10, J12.11, J12.12, J12.13, J12.14, J12.15, J12.16, R2.1, R8.1, U1.4 (GND), U1.6 (FB2), U1.10 (PGND), U1.15 (VSEL), U2.1 (GND), U2.4 (ON), U2.5 (GND), U3.1 (*1OE), U3.5 (2A), U3.7 (GND), U3.9 (3A), U3.12 (4A)
INT: J7.7, J7.8
unnamed: D1.1 (A), R6.1
unnamed: L1.1, U1.11 (L1)
unnamed: L1.2, U1.9 (L2)
unnamed: C4.1, U1.3 (VAUX)
unnamed: R10.2, U3.3 (1Y)
Out: J5.5, R10.1
PS0: J7.3, J7.4
PS1: J7.1, J7.2
RESET: A1.3 (~RESET), J11.3
RST: J8.1, J8.2
SCK: J6.7, J6.8
SCL: J8.5, J8.6
SCL/A5: A1.24 (SCL/A5), J10.9
SDA: J8.3, J8.4
SDA/A4: A1.23 (SDA/A4), J10.8
St: J3.3, R3.2, U2.8 (ST)
VCC: J6.3, J6.4
VDD: J6.1, J6.2
VIN: A1.30 (VIN), J8.11, J8.12, J10.15
VUSB/5V: A1.27 (VUSB/5V), J10.12
Vin: C1.1, C2.1, C3.1, C9.1, J2.1, R1.2, R7.2, U1.12 (13), U1.13
Vin2: J3.1, U2.6 (VIN2)
Vout: C5.1, C6.1, C7.1, C8.1, J1.1, R3.1, R4.2, R6.2, U1.7 (8), U1.8, U2.3 (VIN1)

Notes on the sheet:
Power LED
IMU BNO055
Connectors
VIN: 3-16V
Bit Shift
Buck Boost
HX711 AMP
Shield
VOUT: 2.5-9V
Power Hub
ESP32

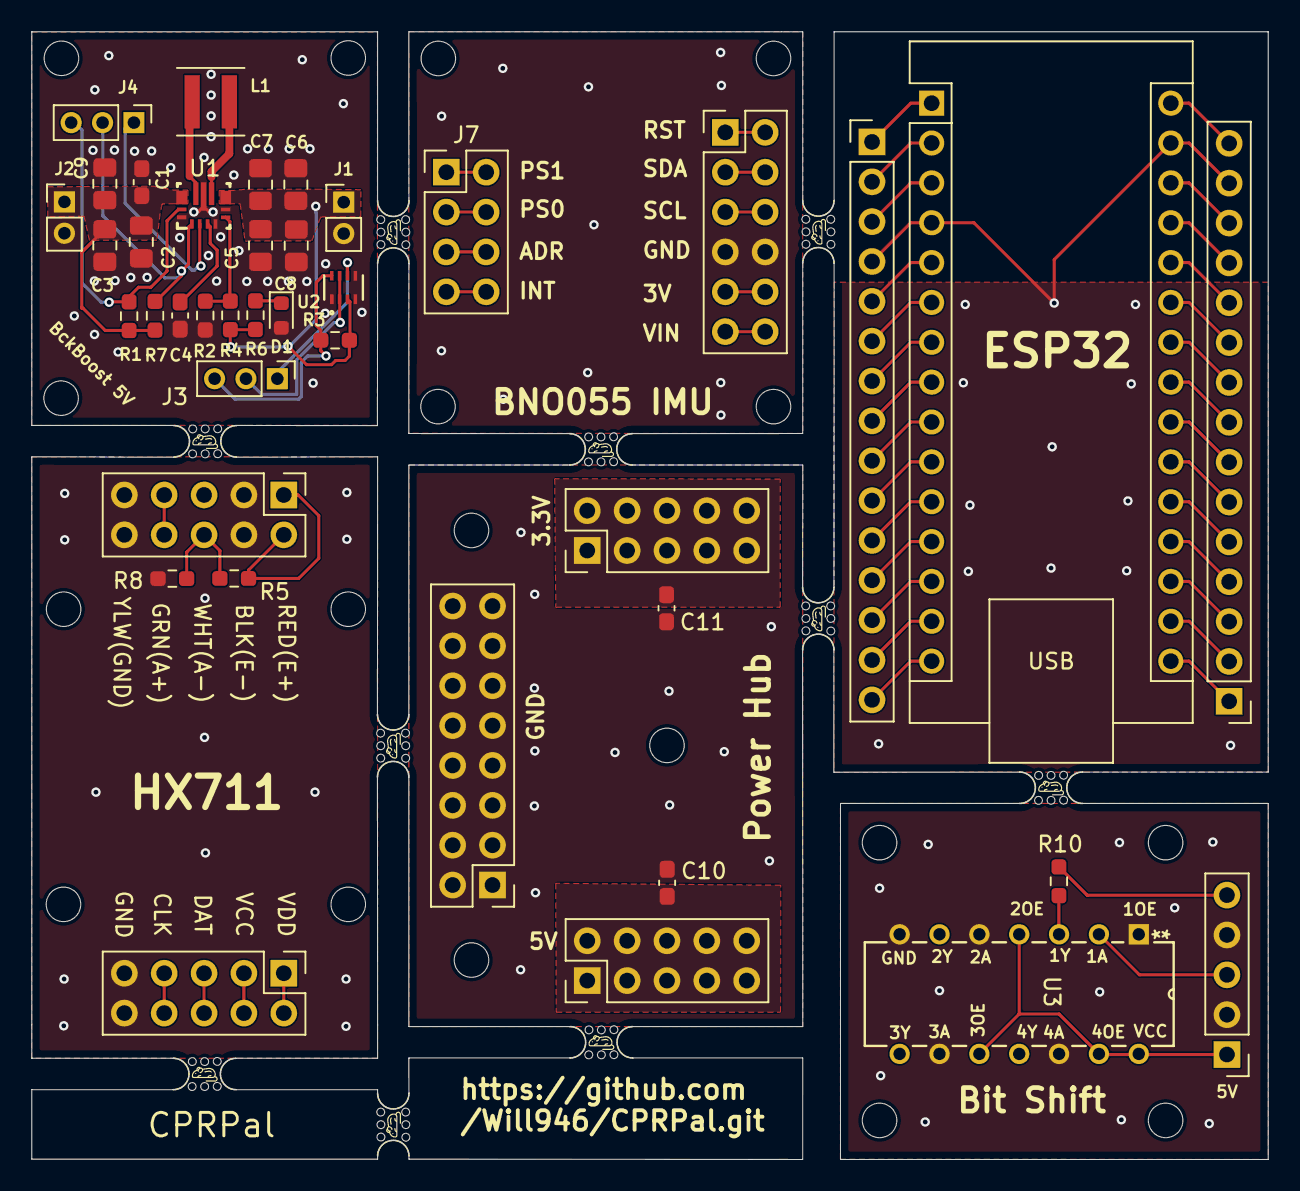
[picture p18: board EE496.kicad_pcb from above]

Board: 2 copper layers, 78.8 x 71.9 mm, 68 parts (0 on the bottom side), 62 nets.

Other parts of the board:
mouse-bite-2mm-4mm, mouse-bite-2mm-4mm#2, mouse-bite-2mm-4mm#3, mouse-bite-2mm-4mm#4, mouse-bite-2mm-4mm#5, mouse-bite-2mm-4mm#6, mouse-bite-2mm-4mm#7, mouse-bite-2mm-4mm#8, mouse-bite-2mm-4mm#9, mouse-bite-2mm-4mm#10: VAL**; mouse-bite-2mm-4mm

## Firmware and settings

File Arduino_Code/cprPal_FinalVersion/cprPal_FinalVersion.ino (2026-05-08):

// ============================================================
//  CPRPal — ESP32 Arduino Firmware
//  A wearable CPR coaching device that monitors compression
//  rate (CPM), compression depth/force, body tilt (IMU), and
//  rescuer heart rate (PPG). Feedback is delivered via a TFT
//  display, NeoPixel LED bars, and a buzzer metronome.
//
//  FreeRTOS Task layout:
//    Core 0 — taskHX711   : reads the load cell + computes CPM
//    Core 0 — taskIMU     : reads BNO055 orientation
//    Core 0 — taskPPG     : pulse-oximetry / heart-rate detection
//    Core 0 — taskBuzzer  : 110 BPM audible + visual metronome
//    Core 1 — loop()      : TFT display + NeoPixel LED bar refresh
// ============================================================

#include "SPI.h"
#include "HX711.h"                   // Load cell amplifier library
#include "Adafruit_GFX.h"            // Core graphics primitives for TFT
#include "Adafruit_ILI9341.h"        // ILI9341 TFT driver
#include <Wire.h>                    // I2C bus (used by BNO055)
#include <Adafruit_Sensor.h>         // Adafruit unified sensor abstraction
#include <Adafruit_BNO055.h>         // BNO055 9-DOF IMU driver
#include <utility/imumaths.h>        // IMU math helpers
#include <Adafruit_NeoPixel.h>       // WS2812B RGB LED strip driver
#include <WiFi.h>                    // ESP32 Wi-Fi stack
#include <HTTPClient.h>              // HTTP POST to cloud endpoint
#include "esp_sleep.h"               // Light/deep sleep APIs
#include "esp_task_wdt.h"            // Task watchdog timer
#include "esp_system.h"              // esp_reset_reason()
#include "driver/gpio.h"             // Low-level GPIO (pull-ups etc.)
#include "driver/rtc_io.h"           // RTC-domain GPIO (survives sleep)
#include "soc/rtc_cntl_reg.h"        // RTC control registers (brownout)

// --- SPLASH / BOOT ANIMATION IMAGE SUPPORT ---
#include <SdFat_Adafruit_Fork.h>     // SD card FAT filesystem
#include <Adafruit_SPIFlash.h>       // Alternatively, SPI flash storage
#include <Adafruit_ImageReader.h>    // BMP image reader for TFT

// ── Forward declarations ──────────────────────────────────────────────────────
// Declared here so functions defined later can be referenced before they appear.
void taskHX711(void* pvParameters);
void taskIMU(void* pvParameters);
void taskPPG(void* pvParameters);
void taskBuzzer(void* pvParameters);
void prepareWiFiForTraining();
void showModeSelectScreen();
void resetLiveSessionMetrics();
void reinitializeHX711();

// ──────────────────────────────────────────────────────────────────────────────
//  START BUTTON
//  D6 is used as the single physical button: short press = Emergency mode,
//  hold 3 s = Training mode, hold 2 s from sleep = wake.
// ──────────────────────────────────────────────────────────────────────────────
#define START_BUTTON D6

// ──────────────────────────────────────────────────────────────────────────────
//  STORAGE SELECTION
//  Define USE_SD_CARD to load boot BMP files from an SD card;
//  comment it out to use the onboard SPI flash instead.
// ──────────────────────────────────────────────────────────────────────────────
#define USE_SD_CARD
#define SD_CS 4   // SD card chip-select pin

#if defined(USE_SD_CARD)
  SdFat SD;                          // SD FAT filesystem instance
  Adafruit_ImageReader reader(SD);   // BMP reader backed by SD
#else
  // SPI Flash fallback (e.g., Adafruit QSPIFlash on SAMD)
  Adafruit_FlashTransport_SPI flashTransport(SS, &SPI);
  Adafruit_SPIFlash flash(&flashTransport);
  FatVolume filesys;
  Adafruit_ImageReader reader(filesys);
#endif

// ──────────────────────────────────────────────────────────────────────────────
//  HX711 LOAD CELL AMPLIFIER
//  DOUT = serial data out from HX711
//  CLK  = clock pin driven by MCU
// ──────────────────────────────────────────────────────────────────────────────
#define DOUT 3
#define CLK  2

HX711 scale;                         // HX711 driver instance
float calibration_factor = 6500;     // Scale factor (raw counts → lbs);
                                     // adjust via serial '+'/'-' commands

// ──────────────────────────────────────────────────────────────────────────────
//  ILI9341 TFT (240×320 px, SPI)
//  TFT_DC = data/command select
//  TFT_CS = chip select
// ──────────────────────────────────────────────────────────────────────────────
#define TFT_DC 9
#define TFT_CS 10
Adafruit_ILI9341 tft = Adafruit_ILI9341(TFT_CS, TFT_DC);

// ──────────────────────────────────────────────────────────────────────────────
//  BNO055 9-DOF IMU
//  Connected via I2C at address 0x28 on the Wire bus (pins A4/A5).
// ──────────────────────────────────────────────────────────────────────────────
Adafruit_BNO055 bno = Adafruit_BNO055(55, 0x28, &Wire);

// ──────────────────────────────────────────────────────────────────────────────
//  NEOPIXEL LED STRIPS
//
//  strip       — 15-pixel force/depth bar graph on the main housing
//  rhythmStrip — 13-pixel visual metronome strip (flashes at 110 BPM)
//
//  NOTE: LED_PIN (2) is shared with HX711 CLK — this works because
//  NeoPixel bit-banging only happens on Core 1 while HX711 runs on Core 0,
//  but ideally these should be separate pins in a hardware revision.
// ──────────────────────────────────────────────────────────────────────────────
#define LED_PIN    2
#define LED_COUNT  15
Adafruit_NeoPixel strip(LED_COUNT, LED_PIN, NEO_GRB + NEO_KHZ800);

#define RHYTHM_LED_PIN   4
#define RHYTHM_LED_COUNT 13
Adafruit_NeoPixel rhythmStrip(RHYTHM_LED_COUNT, RHYTHM_LED_PIN, NEO_GRB + NEO_KHZ800);

// ──────────────────────────────────────────────────────────────────────────────
//  PULSE OXIMETRY (PPG)
//  PULSE_PIN   — analog input connected to the PulseSensor / photodiode
//  PPG_LED_PIN — indicator LED that flashes on each detected heartbeat
// ──────────────────────────────────────────────────────────────────────────────
#define PULSE_PIN    23
#define PPG_LED_PIN  21

// ──────────────────────────────────────────────────────────────────────────────
//  BUZZER (110 BPM METRONOME)
//  Uses the ESP32 LEDC (PWM) peripheral so the tone is hardware-generated
//  and does not block the CPU.
//  BUZZER_PERIOD_MS = 60 000 / 100 BPM ≈ 600 ms per beat
// ──────────────────────────────────────────────────────────────────────────────
#define BUZZER_PIN       19
#define BUZZER_CHANNEL   0           // LEDC channel 0
#define BUZZER_FREQ_HZ   2000        // 2 kHz tone — clearly audible
#define BUZZER_BEEP_MS   30          // Beep on-time in milliseconds
#define BUZZER_PERIOD_MS 600         // Full beat period (~100 BPM)

// ──────────────────────────────────────────────────────────────────────────────
//  IDLE / AUTO-SLEEP
//  If no significant force change is detected for IDLE_TIMEOUT_MS the device
//  enters low-power mode. IDLE_DELTA_LB is the minimum weight change (lbs)
//  that counts as "activity". WAKE_HOLD_MS is how long the button must be
//  held to wake the device back up.
// ──────────────────────────────────────────────────────────────────────────────
#define IDLE_TIMEOUT_MS   20000UL    // 20 seconds without activity → sleep
#define IDLE_DELTA_LB     10.0f      // ±10 lb change resets the idle timer
#define WAKE_HOLD_MS      2000UL     // Hold button 2 s to wake from sleep

// ──────────────────────────────────────────────────────────────────────────────
//  PPG SIGNAL CONSTANTS
//  FINGER_ON         — ADC threshold below which no finger is detected
//  PPG_AVG_COUNT     — rolling average window (smooths noise)
//  MIN/MAX_BEAT_INTERVAL — clamp valid inter-beat intervals (ms)
//                         equates to ~20–200 BPM
// ──────────────────────────────────────────────────────────────────────────────
const int          FINGER_ON         = 1700;
const int          PPG_AVG_COUNT     = 10;
const int          MIN_BEAT_INTERVAL = 300;   // ≈ 200 BPM max
const int          MAX_BEAT_INTERVAL = 3000;  // ≈  20 BPM min

// ──────────────────────────────────────────────────────────────────────────────
//  CPM (COMPRESSIONS PER MINUTE) DETECTION
//  FORCE_THRESHOLD_LB — minimum force (lbs) to count as a compression
//  CPM_TIMEOUT_MS     — reset CPM if no compression for this long
//  CPM_DEBOUNCE_MS    — ignore edges faster than this (anti-bounce)
//  CPM_INTERVAL_COUNT — number of recent intervals averaged for CPM
// ──────────────────────────────────────────────────────────────────────────────
const float        FORCE_THRESHOLD_LB   = 30.0f;
const unsigned long CPM_TIMEOUT_MS    = 2000UL;
const unsigned long CPM_DEBOUNCE_MS   = 180UL;
const int          CPM_INTERVAL_COUNT = 6;

// ──────────────────────────────────────────────────────────────────────────────
//  WI-FI / CLOUD ENDPOINT
//  Wi-Fi is only enabled during Training mode; it is fully shut down for
//  Emergency mode to conserve power and reduce latency.
// ──────────────────────────────────────────────────────────────────────────────
const char* WIFI_SSID     = "GalaxyS24FE99E2";
const char* WIFI_PASSWORD = "chickenbutt";
const char* SENSOR_ENDPOINT =
  "https://gentle-stone-0c20e761e.6.azurestaticapps.net/api/sensor";

// ──────────────────────────────────────────────────────────────────────────────
//  DEVICE MODES
//  MODE_WAITING   — idle / mode-selection screen
//  MODE_EMERGENCY — real cardiac event; no Wi-Fi, minimal overhead
//  MODE_TRAINING  — 2-minute timed practice session with cloud upload
// ──────────────────────────────────────────────────────────────────────────────
enum DeviceMode {
  MODE_WAITING = 0,
  MODE_EMERGENCY,
  MODE_TRAINING
};

// Training session timing constants
const unsigned long TRAINING_HOLD_MS    = 3000UL;    // Hold time (ms) to select training
const unsigned long TRAINING_SESSION_MS = 120000UL;  // Session length: 2 minutes
const unsigned long TRAINING_SAMPLE_MS  = 3000UL;    // Sample metrics every 3 s

// ──────────────────────────────────────────────────────────────────────────────
//  RTC MEMORY — persists across soft resets and deep sleep cycles.
//  Used to keep a rolling log of recent reset reasons for diagnostics.
// ──────────────────────────────────────────────────────────────────────────────
RTC_DATA_ATTR int     rtc_resetCount    = 0;
RTC_DATA_ATTR uint8_t rtc_resetLog[10]  = {0};  // Circular log of last 10 resets

// ──────────────────────────────────────────────────────────────────────────────
//  RTOS SYNCHRONISATION PRIMITIVES
//  xDataMutex — protects all shared sensor/state variables (g_xxx)
//  xWireMutex — protects the I2C bus (shared between IMU and potentially PPG)
// ──────────────────────────────────────────────────────────────────────────────
SemaphoreHandle_t xDataMutex;
SemaphoreHandle_t xWireMutex;

// ──────────────────────────────────────────────────────────────────────────────
//  SHARED SENSOR STATE
//  All variables prefixed g_ are written by sensor tasks (Core 0) and read
//  by the display loop (Core 1). Every access must be wrapped with
//  xSemaphoreTake(xDataMutex) / xSemaphoreGive(xDataMutex).
// ──────────────────────────────────────────────────────────────────────────────

// — Load cell / force —
volatile float  g_currentWeight    = 0.0f;  // Current filtered force (lbs)
volatile float  g_filteredWeight   = 0.0f;  // Same as above (kept for clarity)
volatile float  g_currentRawWeight = 0.0f;  // Un-filtered raw reading (lbs)
volatile float  g_maxWeight        = 0.0f;  // Peak force seen this session (lbs)
volatile float  g_compressionRate  = 0.0f;  // Rolling-average CPM

// — IMU orientation (relative to calibration baseline) —
volatile float  g_currentHeading   = 0.0f;  // Yaw  delta from baseline (°)
volatile float  g_currentRoll      = 0.0f;  // Roll delta from baseline (°)
volatile float  g_currentPitch     = 0.0f;  // Pitch delta from baseline (°)
volatile float  g_baseHeading      = 0.0f;  // Baseline yaw  captured at startup
volatile float  g_baseRoll         = 0.0f;  // Baseline roll
volatile float  g_basePitch        = 0.0f;  // Baseline pitch
volatile bool   g_imuBaselineReady = false; // True once baseline is captured
char            g_imuPostureStatus[16] = "Waiting";  // "Good" / "Adjust" / "Lean"

// — PPG / heart rate —
volatile int    g_currentSignal = 0;          // Latest PPG ADC reading
volatile int    g_currentBPM    = 0;          // Estimated BPM (0 = no reading)
char            g_ppgStatus[16] = "No heartbeat"; // Human-readable status

// — Control flags (set by UI / idle logic, consumed by tasks) —
volatile bool   g_doTare      = false;  // When true, taskHX711 re-tares the scale
volatile bool   g_resetMax    = false;  // When true, clears g_maxWeight
volatile bool   g_goToSleep   = false;  // When true, loop() triggers low-power mode

// — Idle tracking —
volatile unsigned long g_lastActivityTime = 0;  // millis() of last detected activity

// — Session / mode state —
volatile DeviceMode g_mode           = MODE_WAITING;
volatile bool       g_sessionRunning = false;  // Buzzer/metronome active only when true

// ──────────────────────────────────────────────────────────────────────────────
//  TRAINING SESSION ACCUMULATORS
//  Sampled every TRAINING_SAMPLE_MS; averaged and uploaded at session end.
// ──────────────────────────────────────────────────────────────────────────────
unsigned long g_trainingStartTime   = 0;
unsigned long g_lastTrainingSample  = 0;
bool          g_trainingResultsSent = false;

float g_sumAvgWeight    = 0.0f;
float g_sumMaxWeight    = 0.0f;
float g_sumCompRate     = 0.0f;
float g_sumPPGSignal    = 0.0f;
float g_sumBPM          = 0.0f;
float g_sumPitch        = 0.0f;
float g_sumRoll         = 0.0f;
int   g_trainingSamples = 0;

// ──────────────────────────────────────────────────────────────────────────────
//  TASK HANDLES — used to suspend, resume, or delete tasks dynamically.
// ──────────────────────────────────────────────────────────────────────────────
TaskHandle_t hHX711  = NULL;
TaskHandle_t hIMU    = NULL;
TaskHandle_t hPPG    = NULL;
TaskHandle_t hBuzzer = NULL;

// ──────────────────────────────────────────────────────────────────────────────
//  SENSOR DATA STRUCT — packed before serialising to JSON for cloud upload.
// ──────────────────────────────────────────────────────────────────────────────
struct SensorData {
  String deviceId;
  String timestamp;
  String mode;
  String sessionType;
  int ppg;                   // Raw PPG signal value
  float imuX;                // IMU X (heading) — currently unused in uploads
  float imuY;                // IMU Y (roll)
  float imuZ;                // IMU Z (pitch)
  int compressionRate;       // CPM rounded to int
  float compressionDepth;    // Average force in lbs (proxy for depth)
  int recoil;                // 1 = full recoil detected, 0 = incomplete
  String status;             // Human-readable quality summary
  int sampleCount;           // Number of 3-second samples in session
  unsigned long sessionDurationMs; // Total session duration in ms
};

// ──────────────────────────────────────────────────────────────────────────────
//  UTILITY HELPERS
// ──────────────────────────────────────────────────────────────────────────────

/**
 * Wrap an angle (degrees) into the range [-180, +180].
 * Used when computing relative IMU orientation deltas.
 */
static float wrapAngle(float a) {
  while (a >  180.0f) a -= 360.0f;
  while (a < -180.0f) a += 360.0f;
  return a;
}

/**
 * Convert an esp_reset_reason_t enum value to a human-readable string.
 * Used in the boot diagnostic printout.
 */
static const char* resetReasonToString(esp_reset_reason_t reason) {
  switch (reason) {
    case ESP_RST_POWERON:   return "POWERON";
    case ESP_RST_EXT:       return "EXTERNAL";
    case ESP_RST_SW:        return "SOFTWARE";
    case ESP_RST_PANIC:     return "PANIC";
    case ESP_RST_INT_WDT:   return "INT_WDT";
    case ESP_RST_TASK_WDT:  return "TASK_WDT";
    case ESP_RST_WDT:       return "OTHER_WDT";
    case ESP_RST_BROWNOUT:  return "BROWNOUT";
    case ESP_RST_DEEPSLEEP: return "DEEPSLEEP";
    default:                return "UNKNOWN";
  }
}

/**
 * Returns the current uptime as a string (milliseconds since boot).
 * Used as a lightweight timestamp for cloud payloads when NTP is unavailable.
 */
String getTimestampString() {
  return String(millis());
}
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
void loop() {
  unsigned long now = millis();

  // ── Check sleep flag ──────────────────────────────────────────────────────
  bool       shouldSleep = false;
  DeviceMode modeCopy;
  xSemaphoreTake(xDataMutex, portMAX_DELAY);
  shouldSleep = g_goToSleep;
  modeCopy    = g_mode;
  xSemaphoreGive(xDataMutex);

  if (shouldSleep) {
    enterLowPowerMode();
    return;  // enterLowPowerMode() blocks; returns here only after wake
  }

  // ── Re-enter mode selection if session ended ──────────────────────────────
  if (modeCopy == MODE_WAITING) {
    showModeSelectScreen();
    DeviceMode selectedMode = waitForModeSelection();
    captureIMUBaseline();
    if (selectedMode == MODE_TRAINING) startTrainingMode();
    else                               startEmergencyMode();
    return;
  }

  // ── Serial calibration commands ───────────────────────────────────────────
  if (Serial.available()) {
    char c = Serial.read();
    if      (c == '+' || c == 'a') { calibration_factor += 10; scale.set_scale(calibration_factor); }
    else if (c == '-' || c == 'z') { calibration_factor -= 10; scale.set_scale(calibration_factor); }
    else if (c == 't' || c == 'T') { xSemaphoreTake(xDataMutex, portMAX_DELAY); g_doTare   = true; xSemaphoreGive(xDataMutex); }
    else if (c == 'r' || c == 'R') { xSemaphoreTake(xDataMutex, portMAX_DELAY); g_resetMax = true; xSemaphoreGive(xDataMutex); }
  }

  // ── Training session tick ─────────────────────────────────────────────────
  if (modeCopy == MODE_TRAINING) {
    updateTrainingSession();
  }

  // ── NeoPixel bar graph — refresh at ~40 Hz ────────────────────────────────
  if (now - lastLEDUpdate >= 25) {
    lastLEDUpdate = now;
    float w;
    xSemaphoreTake(xDataMutex, portMAX_DELAY);
    w = g_currentWeight;
    xSemaphoreGive(xDataMutex);
    updateBarGraph(w);
  }

  // ── TFT status display — refresh at 10 Hz ────────────────────────────────
  if (now - lastTFTUpdate >= 100) {
    lastTFTUpdate = now;

    // Snapshot all shared values under mutex (minimise lock hold time)
    float curW, compRate, roll, pitch;
    int bpm;
    char ppgStat[16];

    xSemaphoreTake(xDataMutex, portMAX_DELAY);
    curW     = g_currentWeight;
    compRate = g_compressionRate;
    roll     = g_currentRoll;
    pitch    = g_currentPitch;
    bpm      = g_currentBPM;
    strncpy(ppgStat, g_ppgStatus, sizeof(ppgStat) - 1);
    ppgStat[sizeof(ppgStat) - 1] = '\0';
    xSemaphoreGive(xDataMutex);

    // Derive status strings from raw values
    const char* cpmStatus   = getCPMStatus(compRate);
    const char* forceStatus = getForceStatus(curW);
    const char* tiltStatus  = getTiltStatus(roll, pitch);
    const char* heartStatus = getHeartbeatStatus(bpm, ppgStat);

    // Serial monitor log line (useful for debugging without the TFT)
    Serial.printf("CPM: %.1f (%s) | Force: %.1f lb (%s) | Tilt: %s | BPM: %d | %s\n",
                  compRate, cpmStatus, curW, forceStatus, tiltStatus, bpm, heartStatus);

    // ── CPM section (y = 0–55) ────────────────────────────────────────────
    tft.fillRect(0, 20, 320, 35, ILI9341_BLACK);
    if      (strcmp(cpmStatus, "TOO SLOW") == 0) tft.setTextColor(ILI9341_YELLOW);
    else if (strcmp(cpmStatus, "TOO FAST") == 0) tft.setTextColor(ILI9341_RED);
    else if (strcmp(cpmStatus, "GOOD") == 0)     tft.setTextColor(ILI9341_GREEN);
    else                                         tft.setTextColor(ILI9341_WHITE);

    tft.setTextSize(2);
    tft.setCursor(20, 20);
    if (modeCopy == MODE_TRAINING) {
      // Training: show numeric value and status
      tft.print(compRate, 0);
      tft.print(" cpm  ");
      tft.print(cpmStatus);
    } else {
      // Emergency: status only (less screen clutter)
      tft.print(cpmStatus);
    }

    // ── Force section (y = 90–130) ───────────────────────────────────────
    tft.fillRect(0, 90, 320, 36, ILI9341_BLACK);
    if      (strcmp(forceStatus, "TOO LIGHT") == 0)  tft.setTextColor(ILI9341_YELLOW);
    else if (strcmp(forceStatus, "TOO STRONG") == 0) tft.setTextColor(ILI9341_RED);
    else                                             tft.setTextColor(ILI9341_GREEN);

    tft.setCursor(20, 90);
    tft.print(forceStatus);
    if (modeCopy == MODE_TRAINING) {
      // Training: show numeric force value below the status label
      tft.setCursor(20, 112);
      tft.print(curW, 1);
      tft.print(" lb");
    }

    // ── Tilt section (y = 170–210) ───────────────────────────────────────
    tft.fillRect(0, 170, 320, 36, ILI9341_BLACK);
    if (strcmp(tiltStatus, "ADJUST") == 0) tft.setTextColor(ILI9341_RED);
    else                                   tft.setTextColor(ILI9341_GREEN);

    tft.setCursor(20, 170);
    tft.print(tiltStatus);
    if (modeCopy == MODE_TRAINING) {
      // Training: show raw roll/pitch angles
      tft.setCursor(20, 192);
      tft.print("R:");
      tft.print(roll, 1);
      tft.print(" P:");
      tft.print(pitch, 1);
    }

    // ── PPG / Heartbeat section (y = 250–320) ────────────────────────────
    tft.fillRect(0, 250, 320, 70, ILI9341_BLACK);
    if (strcmp(heartStatus, "Heartbeat detect") == 0) tft.setTextColor(ILI9341_GREEN);
    else                                              tft.setTextColor(ILI9341_RED);

    tft.setCursor(20, 250);
    tft.print("BPM: ");
    if (bpm > 0) tft.print(bpm);
    else         tft.print("--");  // No valid reading

    tft.setCursor(20, 272);
    tft.print(heartStatus);
  }
}
